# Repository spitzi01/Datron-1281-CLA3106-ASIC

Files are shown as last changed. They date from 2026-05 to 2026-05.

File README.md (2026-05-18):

# Datron-1281-CLA3106-ASIC
Drop-in replacement for Datrons custom ASIC CLA3106 with a 5V CPLD

The Datron 1281 & 1271 multimeters and some Datron products use a custom ASIC for the serial communication inside the instrument. This ASIC in its basic function is nothing more than a bidirectional shift register with error detection. After carefully studying the service manual and making some measurements in my Datron 1281, I was able to replicate the functions of this ASIC. Now a 5V ATMEL CPLD ATF1504 can do the job of this irreplaceable IC. I designed a little PCB which can be installed in a DIP socket. If a CLA3106 breaks, it can be replaced with this PCB. No further modifications are needed.

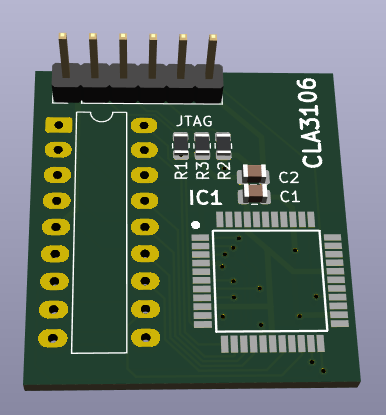
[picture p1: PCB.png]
PCB adapter in KiCAD 3D view


The CPLD can be ordered preprogrammed from Digikey or programmed by yourself, if you have the necessary equipment. The firmware for the ATF1504 ist in the CLA3106.jed file. The KiCAD project files, Gerber and BOM are all in this repository. I hope with this project some old Datron equipment can be saved.

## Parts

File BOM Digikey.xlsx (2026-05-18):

Digi-Key: Warenkorb
Index | Menge | Teilenummer | Hersteller-Teilenummer | Beschreibung | Kundenreferenz | Verfügbar | Lieferrückstände | Stückpreis | Gesamtpreis EUR
1 | 1 | 1276-6840-1-ND | CL21B104KCFNNNE | CAP CER 0.1UF 100V X7R 0805 |  | 1 | 0 | 0.09 | 0.09
2 | 1 | 478-KGM21AR72A105KUCT-ND | KGM21AR72A105KU | CAP CER 1UF 100V X7R 0805 |  | 1 | 0 | 0.29 | 0.29
3 | 3 | 2019-RK73H2ATTD1002FCT-ND | RK73H2ATTD1002F | RES 10K OHM 1% 1/4W 0805 |  | 3 | 0 | 0.09 | 0.27
4 | 1 | ATF1504AS-10AU44-ND | ATF1504AS-10AU44 | IC CPLD 64MC 10NS 44TQFP |  | 1 | 0 | 4.47 | 4.47
5 | 1 | 1175-1522-5-ND | 220-1-18-003 | CONN HDR DIP MALE PIN 18POS GOLD |  | 1 | 0 | 1.72 | 1.72
6 | 1 | 732-5319-ND | 61300611121 | CONN HEADER VERT 6POS 2.54MM |  | 1 | 0 | 0.27 | 0.27

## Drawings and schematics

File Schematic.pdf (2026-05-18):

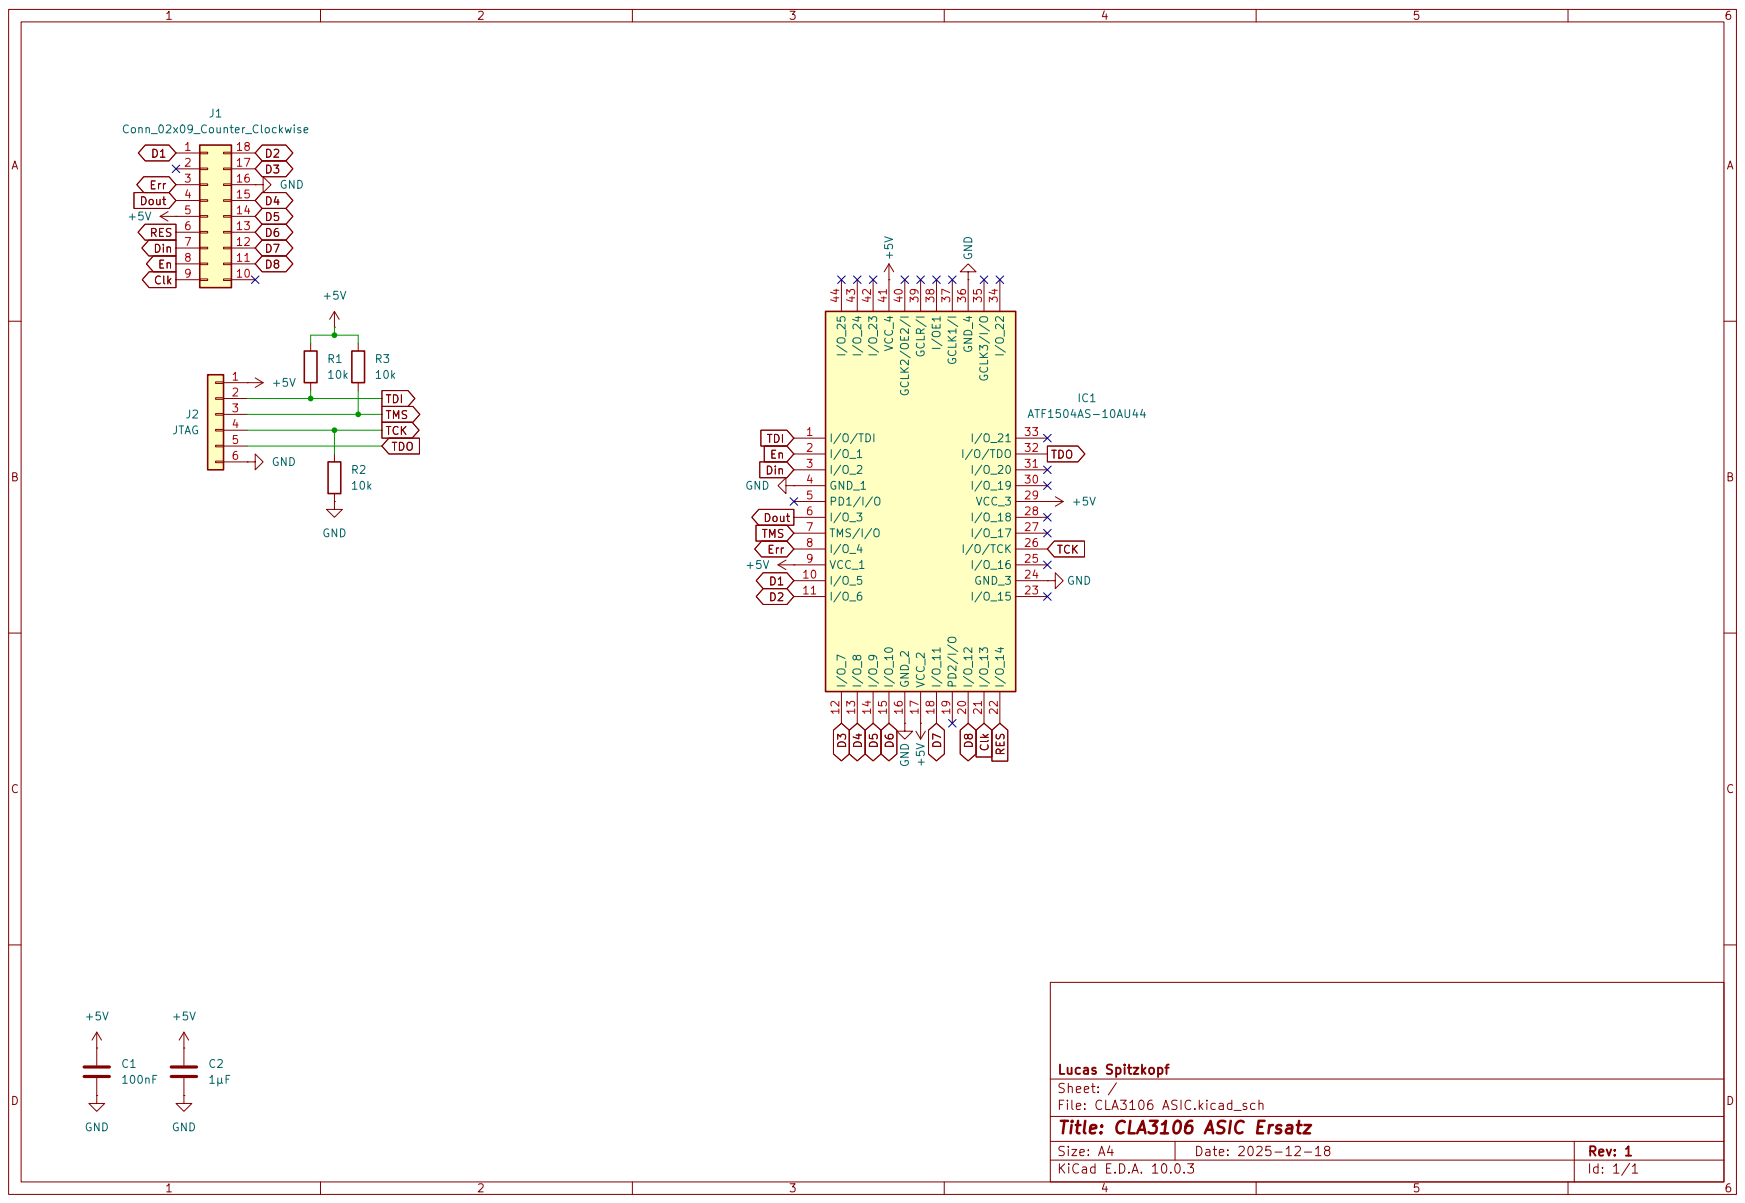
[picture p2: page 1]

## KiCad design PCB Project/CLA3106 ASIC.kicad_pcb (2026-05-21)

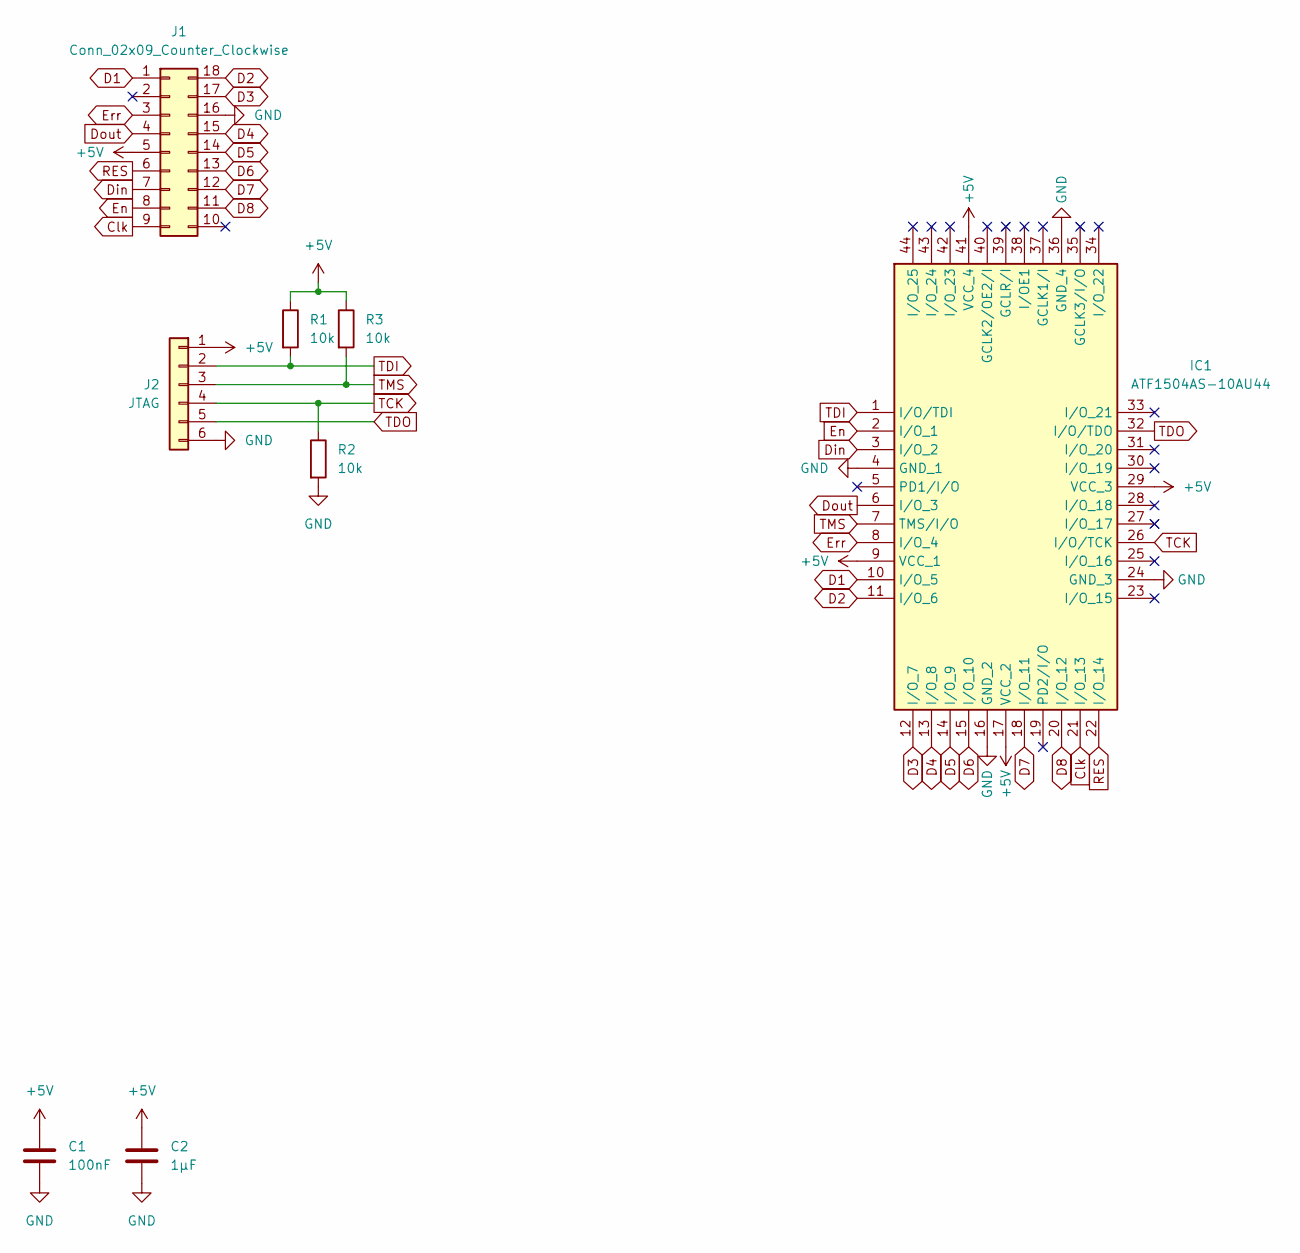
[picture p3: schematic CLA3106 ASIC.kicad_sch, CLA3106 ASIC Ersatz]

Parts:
C1: 100nF; C_0805_2012Metric
C2: 1µF; C_0805_2012Metric
IC1: ATF1504AS-10AU44; QFP80P1200X1200X120-44N; Manufacturer_Part_Number ATF1504ASL-25AU44-T; Mouser Part Number 556-AT1504ASL25AU44T
J1: Conn_02x09_Counter_Clockwise; DIP-18_W7.62mm_LongPads
J2: JTAG; PinHeader_1x06_P2.54mm_Vertical
R1, R2, R3: 10k; R_0805_2012Metric

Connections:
+5V: C1.1, C2.1, IC1.9 (VCC_1), IC1.17 (VCC_2), IC1.29 (VCC_3), IC1.41 (VCC_4), J1.5, J2.1, R1.1, R3.1
Clk: IC1.21 (I/O_13), J1.9
D1: IC1.10 (I/O_5), J1.1
D2: IC1.11 (I/O_6), J1.18
D3: IC1.12 (I/O_7), J1.17
D4: IC1.13 (I/O_8), J1.15
D5: IC1.14 (I/O_9), J1.14
D6: IC1.15 (I/O_10), J1.13
D7: IC1.18 (I/O_11), J1.12
D8: IC1.20 (I/O_12), J1.11
Din: IC1.3 (I/O_2), J1.7
Dout: IC1.6 (I/O_3), J1.4
En: IC1.2 (I/O_1), J1.8
Err: IC1.8 (I/O_4), J1.3
GND: C1.2, C2.2, IC1.4 (GND_1), IC1.16 (GND_2), IC1.24 (GND_3), IC1.36 (GND_4), J1.16, J2.6, R2.2
RES: IC1.22 (I/O_14), J1.6
TCK: IC1.26 (I/O/TCK), J2.4, R2.1
TDI: IC1.1 (I/O/TDI), J2.2, R1.2
TDO: IC1.32 (I/O/TDO), J2.5
TMS: IC1.7 (TMS/I/O), J2.3, R3.2

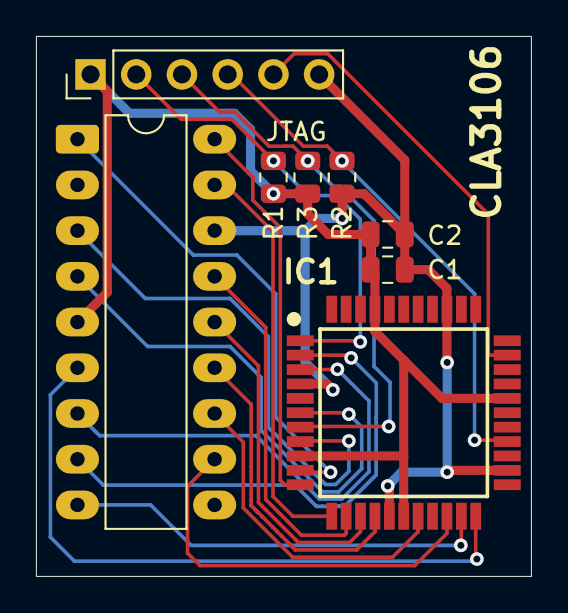
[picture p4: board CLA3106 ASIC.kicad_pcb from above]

Board: 2 copper layers, 27.5 x 30.0 mm, 8 parts (0 on the bottom side), 20 nets.
